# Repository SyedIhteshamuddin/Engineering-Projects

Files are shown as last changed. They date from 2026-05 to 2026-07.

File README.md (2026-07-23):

# Electrical Circuit Projects

This repository contains some of the Arduino and Tinkercad projects I’ve been building while learning embedded systems, sensors, and basic automation concepts.

Most of these projects started as small experiments and gradually improved as I learned more about how sensors, outputs, and system logic work together.

---

## Current Projects

### SAN - (Smart Assistive Navigator)
An assistive navigation system designed to help visually impaired users detect obstacles and unsafe walking surfaces using real-time ultrasonic sensing

### Adaptive Smart Light System
A simple automatic street light simulation using an LDR sensor and adaptive LED brightness control.

### Smart Gas Leakage System
A gas monitoring and alert system that detects gas levels and responds using LEDs, LCD messages, and a buzzer alarm.

More projects and experiments will be added over time as I continue learning.

---

## Project Files

Each project folder usually contains:

- `.ino` file → Arduino code for the project
- `.mp4` file → working demo/simulation video
- `.png` file → circuit design screenshot
- `bom.csv` → components used in the circuit
- `README.md` → explanation of how the project works

---

## Tools Used

- Arduino Uno
- Tinkercad Circuits
- Arduino Blocks + C++
- Sensors, LEDs, buzzers, LCDs, and other basic components

---
## Certificates & Learning

This repository also includes a few engineering-related certificates and learning records connected to:

- MITx Certificate
-Circuit Analysis
-Electronics

- MATLAB
-automation
-embedded systems
-engineering software/tools

- Altium PCB Design Course
 -PCB Designing
 -PCB Manufacturing
 -PCB Simulation

Check Certifications Folder for more details.
---

## Why I Started This Repository

I created this repository to document my progress while exploring electronics and embedded systems.

Right now I’m mainly focused on:
- sensor-based systems
- automation concepts
- Arduino projects
- circuit simulation
- learning how different components interact in a complete system

I’ll continue updating this repository as I build more projects and improve my understanding.

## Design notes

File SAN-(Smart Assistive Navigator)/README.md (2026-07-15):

# Smart Assistive Navigator (SAN)

SAN 1

---






---
## Project Overview
* SAN is An assistive navigation system designed to help visually impaired users detect obstacles and unsafe walking surfaces using real-time ultrasonic sensing.*

Instead of relying on a single warning mechanism, the system communicates danger through **vibration**, **audio alerts**, and a **16×2 LCD**, allowing users to receive immediate feedback depending on the surrounding environment.

The project was developed to explore how embedded systems and simple sensors can be combined to solve real-world accessibility problems.

---
## Demo Video

https://github.com/user-attachments/assets/2c6f290e-6d18-4922-b412-0dd310eef9df

# Problem Statement

Millions of visually impaired individuals rely on traditional white canes for navigation.

While effective for nearby obstacles, they often provide limited awareness of:

- obstacles at head level
- objects farther ahead
- sudden drops
- stairs
- potholes

This project explores a low-cost embedded solution capable of providing earlier warnings through intelligent sensing.

---

# Our Solution

```
          Walking Path
                │
                ▼

     Front Ultrasonic Sensor
                │
                ▼
         Arduino UNO
                │
                │
     Ground Ultrasonic Sensor
                │
                ▼
      Intelligent Decision System
                │
      ┌─────────┼─────────┐
      ▼         ▼         ▼
   LCD      Vibrator    Buzzer
```
## Features

- Dual ultrasonic sensing

- Real-time obstacle detection

- Drop detection

- Adaptive audio alerts

- Adaptive vibration feedback

- LCD monitoring

- Sensor fault detection

- Median filtering

- Boot self-test

- Modular firmware

---
## Hardware Table

| Component | Qty | Purpose |
| --- | --: | --- |
| Arduino Uno | 1 | Main controller |
| HC-SR04 Ultrasonic Sensor | 2 | Obstacle & drop detection |
| 16×2 LCD | 1 | System status |
| Vibration Motor | 1 | Haptic feedback |
| Piezo Buzzer | 1 | Audio feedback |
| NPN Transistor | 1 | Motor driver |
| Breadboard | 1 | Prototype |
| Jumper Wires | — | Connections |

---

SAN - (Smart Assistive Navigator)

---
## Firmware Workflow

```
Read Sensors
      │
      ▼
Filter Sensor Readings
      │
      ▼
Determine Navigation State
      │
      ├── SAFE
      ├── NEAR
      ├── CRITICAL
      ├── DROP
      └── SENSOR ERROR
      │
      ▼
Update LCD
      │
      ▼
Generate Audio & Haptic Alerts
```
---  
## System Workflow

```text
        ┌──────────────┐
        │    START     │
        └──────┬───────┘
               │
               ▼
 Read Front & Ground Sensors
               │
               ▼
    Median Noise Filtering
               │
               ▼
 Navigation State Machine
               │
      ┌────────┼────────┐
      ▼        ▼        ▼
 LCD Update  Vibrator  Buzzer
               │
               ▼
          Repeat Loop
```

---

## Alert System

| State | Vibration | Buzzer |
| --- | --- | --- |
| SAFE | Off | Off |
| NEAR | Slow pulses | Slow beeps |
| CRITICAL | Fast pulses | Fast beeps |
| DROP | Long vibration | High-frequency warning |
| SENSOR ERROR | Error pulse | Error tone |

---
## Repository Structure

```text
Smart-Assistive-Navigator/
│
├── Firmware/
│   └── SAN.ino
│
├── Circuit/
│   └── Tinkercad Design
│
├── Images/
│   ├── Hero.png
│   ├── Circuit.png
│   └── Workflow.png
│
├── Demo/
│   └── Demo.mp4
│
├── BOM/
│   └── Bill_of_Materials.pdf
│
└── README.md
```
---
## Software Architecture

```text
loop()
│
├── Sensor Module
│   ├── Front Sensor
│   └── Ground Sensor
│
├── Signal Processing
│   └── Median Filter
│
├── Decision Engine
│   └── Finite State Machine
│
├── Display Manager
│
├── Alert Controller
│   ├── Vibration Motor
│   └── Piezo Buzzer
│
└── Serial Debug
```
---

## Software Design

The firmware is divided into independent modules to keep the code organized and easier to maintain.

* Sensor acquisition
* Distance filtering
* Navigation state machine
* LCD display manager
* Alert controller
* Boot diagnostics
* Serial debugging

This modular structure made testing and debugging significantly easier during development.

## Engineering Challenges

During development several practical challenges had to be solved:

- Filtering noisy ultrasonic sensor readings
- Preventing false stair detection
- Stabilizing state transitions using hysteresis
- Handling temporary sensor failures
- Designing distinct vibration and buzzer patterns
- Organizing firmware into modular components for easier debugging

## Safety Features

* Sensor failure handling
* Invalid reading rejection
* Cached sensor recovery
* Hysteresis for stable state transitions
* Startup hardware self-test
* Real-time status display

---
## Key Specifications

| Specification | Value |
|---|---|
| Controller | Arduino Uno |
| Programming Language | Embedded C++ |
| Sensors | 2 × HC-SR04 |
| Detection Range | 2–300 cm |
| Drop Detection Threshold | 22 cm |
| Feedback | LCD + Vibration + Buzzer |
| Firmware Architecture | Finite State Machine |
| Signal Processing | Median Filter |

## Future Improvements

Although the current prototype demonstrates the core navigation system, future versions could include:

- Rechargeable battery management

- Waterproof housing

- Voice feedback

- Bluetooth diagnostics

- Lightweight wearable PCB

## What I Learned

Building this project taught me much more than simply connecting sensors to an Arduino.

One thing I didn't expect was how difficult it was to make the sensors reliable. Early versions constantly jumped between states because ultrasonic readings fluctuated. I eventually solved this by combining median filtering, hysteresis, and cached readings instead of relying on raw sensor values. That experience taught me that reliability often comes from small engineering decisions rather than adding more hardware.

Perhaps the biggest lesson was that making a system *reliable* is often more difficult than making it simply *work*.

## Current Status

| Status | Progress |
|---|---|
| Prototype | ✅ Complete |
| Firmware | ✅ Complete |
| Simulation | ✅ Tested |
| Documentation | ✅ Complete |
| Demo Video | ✅ Available |
| GitHub Repository | ✅ Public |
---

## Author

**Syed Ihteshamuddin**

Class 12 Student

Interested in Embedded Systems, Electrical Engineering, and Assistive Technologies.

## Feedback

If you have suggestions, ideas, or improvements for this project, feel free to open an issue or reach out. Constructive feedback is always welcome.
---
## License

This project is shared for educational purposes.

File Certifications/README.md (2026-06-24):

# Certificates

This folder contains certificates completed while exploring engineering tools and technical concepts related to electronics and embedded systems.

Only relevant certifications connected to engineering and technical learning are added here.

---

# Current Certificate

# MITx 6.002.1x: Circuits and Electronics 1

## [MITx 6.002.1x Certificate _ edX.pdf](https://github.com/user-attachments/files/29301755/MITx.6.002.1x.Certificate._.edX.pdf)

---

# MATLAB Onramp

Introductory MATLAB course completed through MathWorks Training Services.
https://matlabacademy.mathworks.com/progress/share/certificate.html?id=902a0990-0046-441e-aec8-c9c82dd8b052&

 ## Next Steps

This repository serves as a foundation for future projects involving

- MATLAB
- Circuit Simulation
- Signal Processing
- Embedded Systems
- Electronics Design

The certificate file is included in this folder.

---

### More learning records and certificates may be added gradually while exploring new engineering concepts and software tools.

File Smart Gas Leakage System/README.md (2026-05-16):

Smart Gas Leakage System

This project is an Arduino + Tinkercad based gas monitoring and alert system built while learning embedded systems and automation concepts.

The system continuously monitors gas levels using a gas sensor and responds with different warning stages based on gas concentration.

---

# Features

- Real-time gas monitoring
- Multi-level gas detection
- SAFE / WARNING / DANGER indication
- LCD status display
- LED alert indicators
- Buzzer alarm during dangerous gas levels
- Serial monitor live sensor values

---

# Components Used

- Arduino Uno
- Gas Sensor
- LCD Display (16x2 I2C)
- LEDs
- Buzzer
- Resistors
- Breadboard
- Tinkercad Circuits
Smart Gas Leakage System
---

# How The System Works

The gas sensor continuously reads surrounding gas concentration levels.

Depending on the sensor value:

- SAFE level → Green LED turns ON
- WARNING level → Yellow LED turns ON
- DANGER level → Red LED + buzzer alarm activate

The LCD display shows:
- current system status
- live gas sensor value

This creates a simple simulation of an automated gas leakage warning system.

---

# Threshold Levels

| Gas Value | System Status |
|---|---|
| Below 307 | No Gas Detected |
| 307 - 499 | SAFE |
| 500 - 699 | WARNING |
| 700+ | DANGER |

---

# What I Learned

While building this project, I learned:

- basics of gas sensors
- analog sensor readings
- threshold-based system logic
- LCD interfacing
- buzzer integration
- multi-output embedded system behavior
- how monitoring systems react to environmental conditions

I also improved my understanding of how sensors, outputs, and decision-making logic work together in embedded systems.

---

# Future Improvements

Some improvements I may explore later:

- GSM alert system
- IoT monitoring
- mobile notifications
- automatic ventilation system
- real hardware implementation

---

# Project Preview



---

# Built Using

- Arduino
- Tinkercad Circuits
- Arduino Blocks + C++

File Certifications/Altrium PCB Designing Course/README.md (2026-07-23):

# Basic PCB Designing Course

**Issued by:** Altium Education

## Overview

Completed the Basic PCB Designing Course provided by Altium Education to learn the fundamentals of professional PCB design.

The course introduces the complete PCB design workflow, from creating schematics to preparing a board for manufacturing.

## Topics Covered

- PCB design fundamentals
- Schematic capture
- PCB layout
- PCB footprints
- Component libraries
- Bill of Materials (BOM)
- Manufacturing workflow
- Basic ECAD concepts

## Why I Took This Course

After building several Arduino projects on breadboards and in Tinkercad, I wanted to learn how electronic products are actually designed for manufacturing.

This course gave me the theoretical foundation needed to begin designing custom PCBs.

## Next Step

I will be applying these concepts by redesigning my **Smart Assistive Navigator (SAN)** project as a custom PCB using **KiCad**, with the goal of producing a manufacturing-ready design.

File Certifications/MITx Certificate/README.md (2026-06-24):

# MITx 6.002.1x: Circuits and Electronics 1

## [MITx 6.002.1x Certificate _ edX.pdf](https://github.com/user-attachments/files/29301755/MITx.6.002.1x.Certificate._.edX.pdf)

## Overview

This repository documents the successful completion of **MITx 6.002.1x: Circuits and Electronics 1 – Basic Circuit Analysis**, offered through MITx and edX.

The course provided a strong foundation in electrical engineering principles and analytical problem solving.

---

## Topics Covered

- Kirchhoff's Current Law (KCL)
- Kirchhoff's Voltage Law (KVL)
- Nodal Analysis
- Thevenin & Norton Equivalents
- Dependent Sources
- Nonlinear Circuits
- Operational Amplifiers
- MOS Logic Fundamentals

---

## Skills Developed

- Circuit Analysis
- Electrical Engineering Fundamentals
- Problem Solving
- Analytical Thinking
- Engineering Mathematics

---

## Certificate

The certificate can be found in:

```
[MITx 6.002.1x Certificate _ edX.pdf](https://github.com/user-attachments/files/29301765/MITx.6.002.1x.Certificate._.edX.pdf)

```

---

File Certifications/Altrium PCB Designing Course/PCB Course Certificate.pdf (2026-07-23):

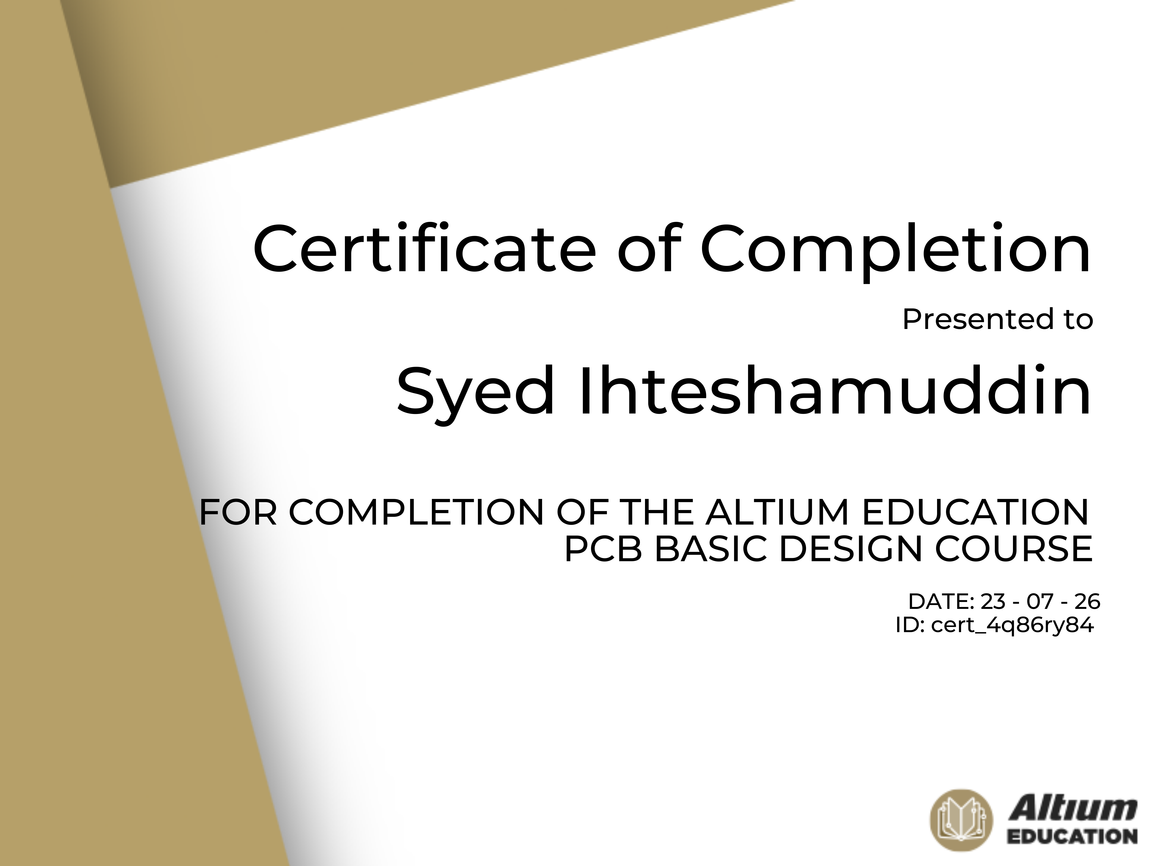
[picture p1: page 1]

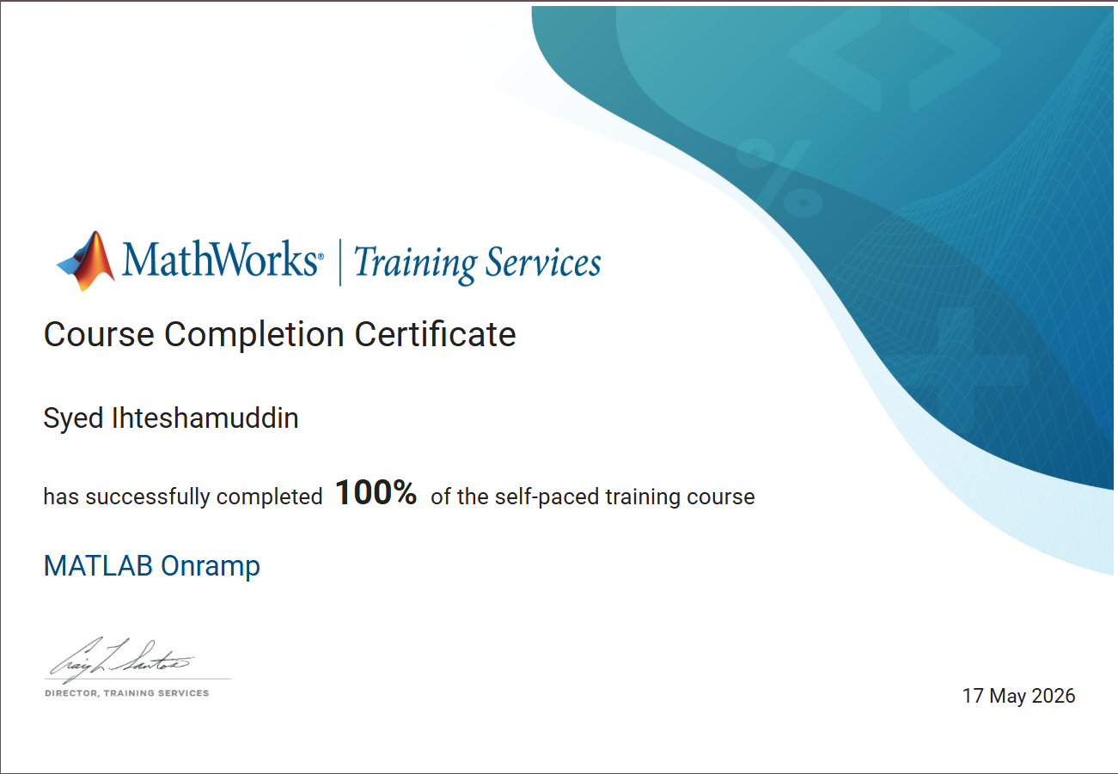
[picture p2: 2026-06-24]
Certifications/MATLAB Onramp/MATLAB Syed Ihteshamuddin Certificate.png

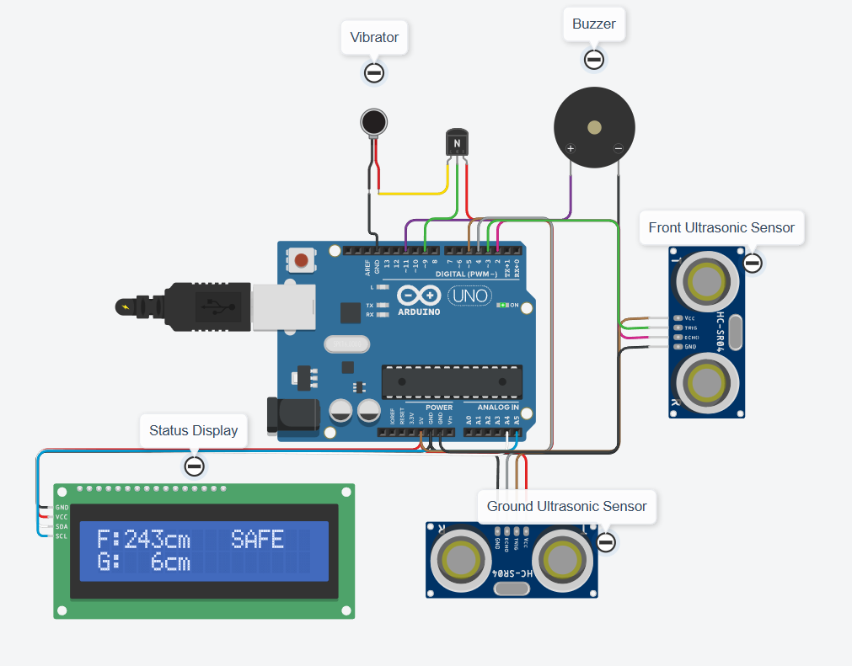
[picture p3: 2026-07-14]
SAN-(Smart Assistive Navigator)/SAN_Hero.png

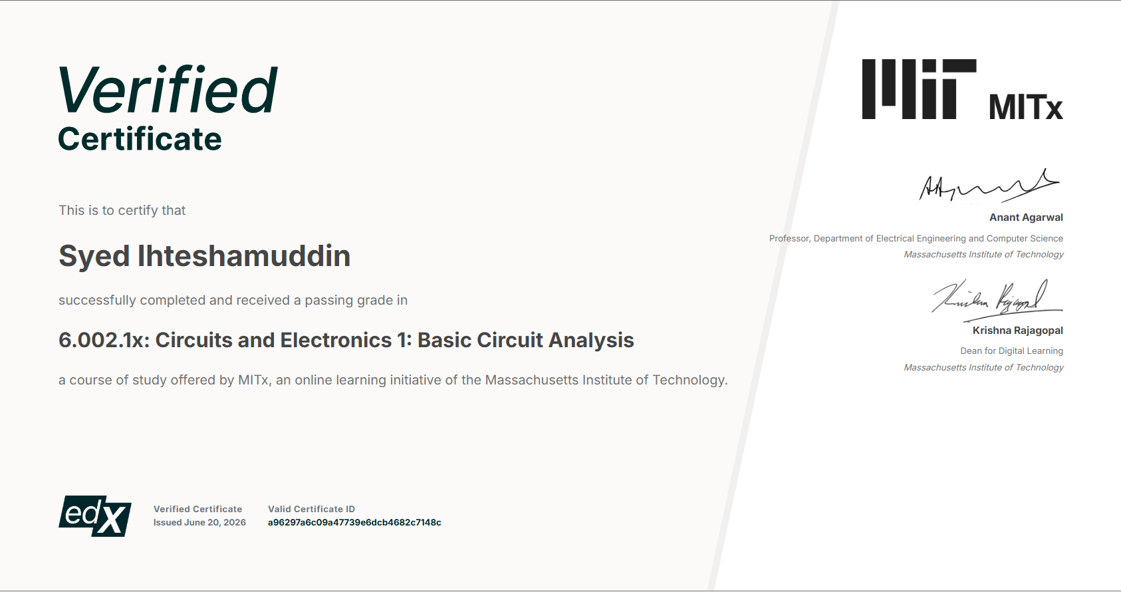
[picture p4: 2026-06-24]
Certifications/MITx Certificate/MIT certificate Photo.png

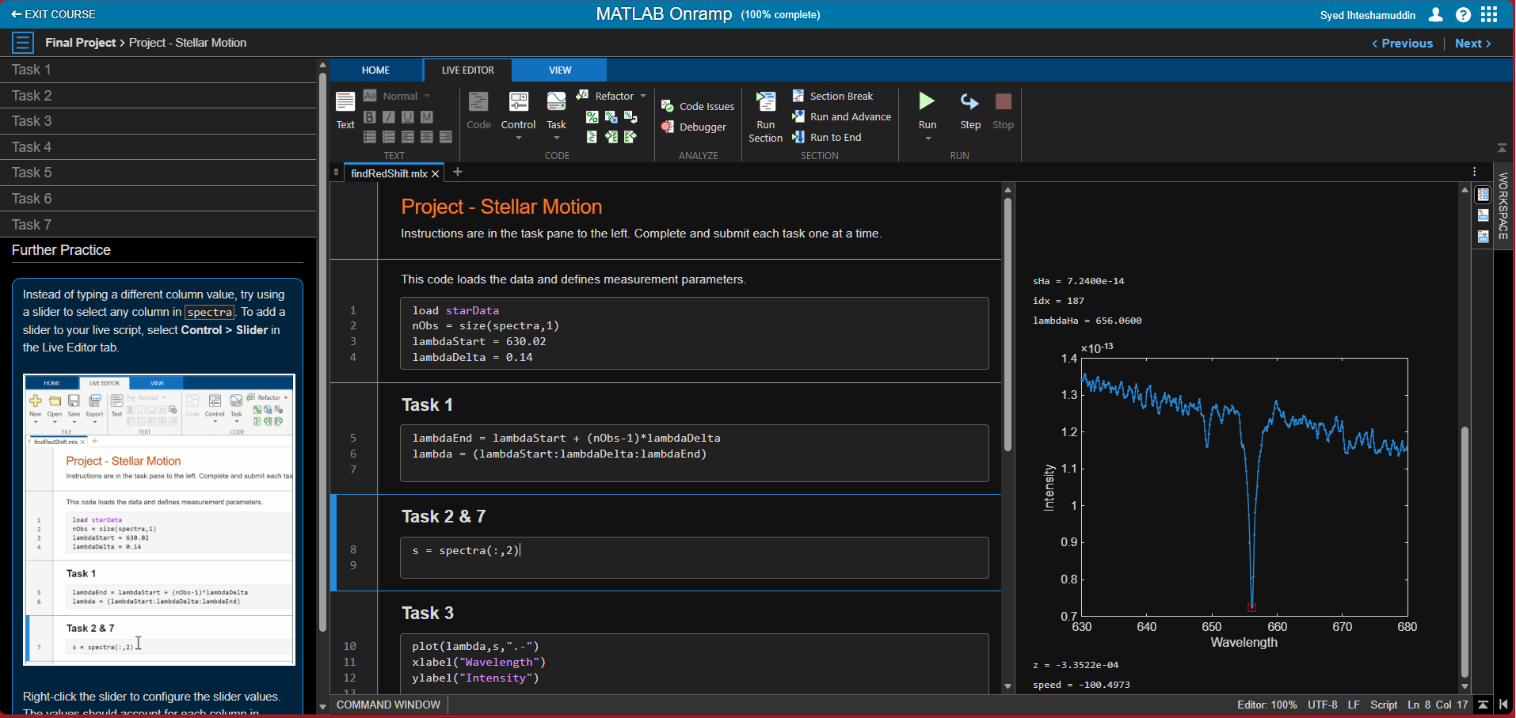
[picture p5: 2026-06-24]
Certifications/MATLAB Onramp/Matlab dashboard.png

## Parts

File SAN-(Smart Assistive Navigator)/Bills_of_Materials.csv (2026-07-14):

Name | Quantity | Component
U1 | 1 | Arduino Uno R3
M1 | 1 | Vibration Motor
T1 | 1 | NPN Transistor (BJT)
PIEZO1 | 1 | Piezo
DISTGroundDistance Measurer, DISTFront Obstacle Measurer | 2 | Ultrasonic Distance Sensor (4-pin)
U2 | 1 | MCP23008-based, 39 (0x27) LCD 16 x 2 (I2C)

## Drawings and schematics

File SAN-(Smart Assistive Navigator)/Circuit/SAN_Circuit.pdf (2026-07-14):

A

1 | 2 | 3 | 4 | 5 | 6

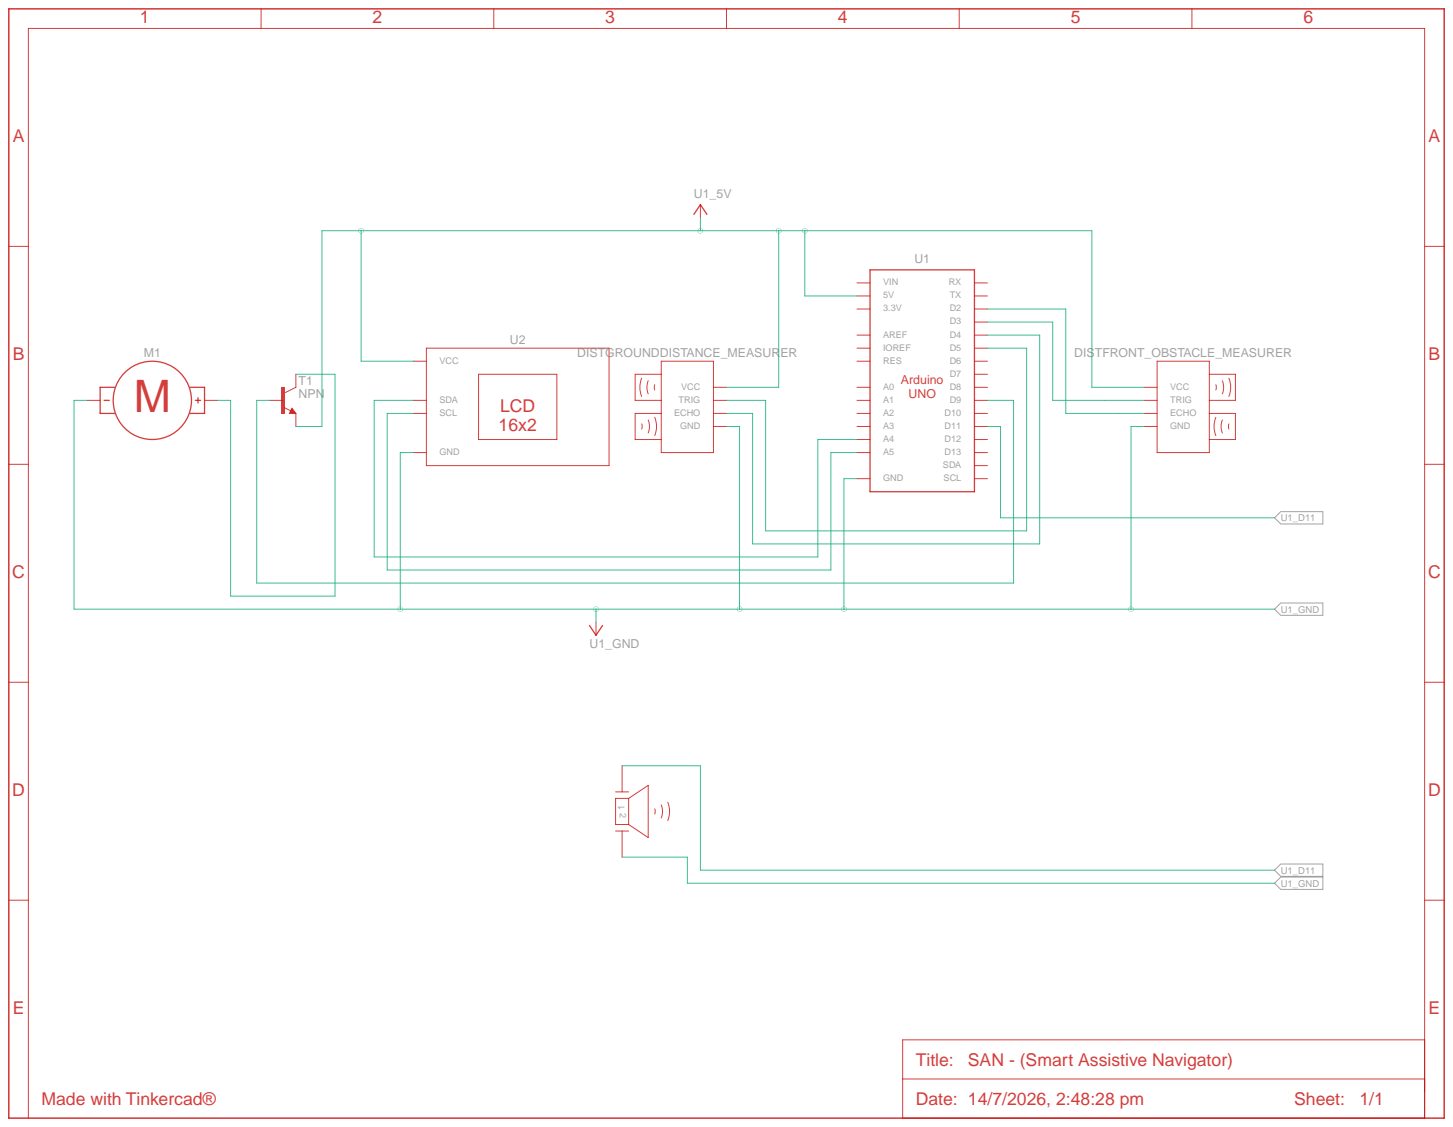
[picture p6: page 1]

Title: SAN - (Smart Assistive Navigator)

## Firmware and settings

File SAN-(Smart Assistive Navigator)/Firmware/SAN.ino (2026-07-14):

/*
===============================================================================
                     SMART ASSISTIVE NAVIGATOR (SAN)
===============================================================================

Firmware Version : 1.0 RC1
Author           : Syed Ihteshamuddin
Platform         : Arduino UNO (ATmega328P)

Project Overview
----------------
Smart Assistive Navigator (SAN) is an embedded assistive mobility system
designed to improve obstacle awareness and drop-off detection for visually
impaired users.

The system continuously monitors the environment using dual ultrasonic sensors,
processes measurements through a robust filtering algorithm, classifies hazards
using a finite state machine with hysteresis, and provides intuitive haptic and
auditory feedback in real time.

===============================================================================
Hardware Configuration
===============================================================================

Microcontroller
---------------
• Arduino UNO R3

Sensors
-------
• HC-SR04 Ultrasonic Sensor (Front Obstacle Detection)
• HC-SR04 Ultrasonic Sensor (Ground / Drop Detection)

Output Devices
--------------
• 16×2 LCD Display (I²C Backpack)
• Vibration Motor
• Piezo Buzzer

===============================================================================
System Features
===============================================================================

✓ Dual Ultrasonic Navigation
✓ Obstacle Detection
✓ Stair / Drop Detection
✓ Median-Based Sensor Filtering
✓ Sensor Failure Recovery
✓ Finite State Machine with Hysteresis
✓ Non-blocking Alert Engine
✓ Intelligent LCD Update Manager
✓ Boot Self-Test Routine
✓ State Transition Alerts
✓ Serial Debug Interface

===============================================================================
Navigation States
===============================================================================

SAFE          : Normal walking condition
NEAR          : Obstacle approaching
CRITICAL      : Immediate obstacle warning
DROP          : Stair / Edge detected
SENSOR_ERROR  : Sensor communication failure

===============================================================================
Pin Configuration
===============================================================================

Front Ultrasonic
----------------
Trigger : D3
Echo    : D2

Ground Ultrasonic
-----------------
Trigger : D5
Echo    : D4

Output Devices
--------------
Motor  : D9
Buzzer : D11

LCD
---
I²C Backpack

===============================================================================
Copyright
===============================================================================

Developed as an independent embedded systems project for educational,
engineering portfolio, and assistive technology research purposes.

===============================================================================
*/

#include <Adafruit_LiquidCrystal.h>

Adafruit_LiquidCrystal lcd(7);

// ---------------- PIN DEFINITIONS ----------------

const byte FRONT_TRIG = 3;
const byte FRONT_ECHO = 2;

const byte GROUND_TRIG = 5;
const byte GROUND_ECHO = 4;

const byte MOTOR_PIN = 9;
const byte BUZZER_PIN = 11;

//---------------- THRESHOLDS ----------------

const int SAFE_DISTANCE = 150;
const int SAFE_EXIT     = 160;

const int CRITICAL_DISTANCE = 75;
const int CRITICAL_EXIT     = 85;

const int DROP_DISTANCE = 22;
const int DROP_EXIT     = 14;

// ---------------- STATES ----------------

enum NavigationState
{
  SAFE,
  NEAR,
  CRITICAL,
  DROP,
  SENSOR_ERROR
};

NavigationState currentState = SAFE;
NavigationState previousState = SENSOR_ERROR;

// ---------------- DISTANCES ----------------

int frontDistance = 0;
int groundDistance = 0;

// ---------------- SENSOR CACHE ----------------

int lastFrontDistance = 150;
int lastGroundDistance = 10;

byte frontFailCount = 0;
byte groundFailCount = 0;

const byte MAX_SENSOR_FAILURES = 5;

byte dropDetectCount = 0;
byte dropClearCount = 0;

const byte DROP_CONFIRM_COUNT = 3;
const byte DROP_CLEAR_COUNT = 3;


//--------------------------------------------------
// LCD CACHE
//--------------------------------------------------

int oldFront = -999;
int oldGround = -999;

NavigationState oldLCDState = SENSOR_ERROR;

// --------------------------------------------------
// ALERT ENGINE VARIABLES
// --------------------------------------------------

unsigned long alertTimer = 0;
unsigned long lcdTimer = 0;

bool alertOutput = LOW;

int alertOnTime = 0;
int alertOffTime = 0;

int buzzerFrequency = 0;


//---------- GLOBAL OUTPUT CONTROL VARIABLES------------



long readUltrasonic(byte trigPin, byte echoPin)
{
  pinMode(trigPin, OUTPUT);

  digitalWrite(trigPin, LOW);
  delayMicroseconds(2);

  digitalWrite(trigPin, HIGH);
  delayMicroseconds(10);

  digitalWrite(trigPin, LOW);

  pinMode(echoPin, INPUT);

  long duration = pulseIn(echoPin, HIGH, 30000);

  if(duration==0)
      return -1;

  return duration;
}

// --------------------------------------------------

int getDistanceCM(byte trig, byte echo)
{
    long duration = readUltrasonic(trig, echo);

    if (duration == -1)
        return -1;

    int distance = duration * 0.01723;

    if (distance < 2 || distance > 300)
        return -1;

    return distance;
}

// --------------------------------------------------
// SENSOR ACQUISITION & FILTERING
// --------------------------------------------------

int medianDistance(byte trig, byte echo)
{
    int sample[3];
    int validCount = 0;

    // Collect three readings
    for(int i = 0; i < 3; i++)
    {
        int d = getDistanceCM(trig, echo);

        if(d != -1)
        {
            sample[validCount++] = d;
        }

        delay(2);
    }

    // No valid readings
    if(validCount == 0)
        return -1;

    // One valid reading
    if(validCount == 1)
        return sample[0];

    // Two valid readings
    if(validCount == 2)
        return (sample[0] + sample[1]) / 2;

    // Three valid readings -> median
    if(sample[0] > sample[1])
    {
        int t = sample[0];
        sample[0] = sample[1];
        sample[1] = t;
    }

    if(sample[1] > sample[2])
    {
        int t = sample[1];
        sample[1] = sample[2];
        sample[2] = t;
    }

    if(sample[0] > sample[1])
    {
        int t = sample[0];
        sample[0] = sample[1];
        sample[1] = t;
    }

    return sample[1];
}
//--------------------------------------------------
// Reads and validates ultrasonic sensor data.
//--------------------------------------------------
void readSensors()
{
    int newFront = medianDistance(FRONT_TRIG, FRONT_ECHO);
    int newGround = medianDistance(GROUND_TRIG, GROUND_ECHO);

    //---------------- FRONT SENSOR ----------------

    if(newFront == -1)
    {
        frontFailCount++;

        if(frontFailCount >= MAX_SENSOR_FAILURES)
            frontDistance = -1;
        else
            frontDistance = lastFrontDistance;
    }
 else
{
    frontFailCount = 0;
    frontDistance = newFront;
    lastFrontDistance = newFront;
}
    //---------------- GROUND SENSOR ----------------

    if(newGround == -1)
    {
        groundFailCount++;

        if(groundFailCount >= MAX_SENSOR_FAILURES)
            groundDistance = -1;
        else
            groundDistance = lastGroundDistance;
    }
  else
{
    groundFailCount = 0;
    groundDistance = newGround;
    lastGroundDistance = newGround;
}
  }

//--------------------------------------------------
// NAVIGATION STATE MACHINE (HYSTERESIS)
//--------------------------------------------------

// Determines navigation state using hysteresis.

void determineState()
 {
    if(frontDistance == -1 || groundDistance == -1)
{
    currentState = SENSOR_ERROR;
    return;
}

    switch(currentState)
    {

        //---------------- SAFE ----------------

        case SAFE:

            if(groundDistance > DROP_DISTANCE)
{
    dropDetectCount++;

    if(dropDetectCount >= DROP_CONFIRM_COUNT)
    {
        currentState = DROP;
        dropDetectCount = 0;
    }
}
else
{
    dropDetectCount = 0;

    if(frontDistance < CRITICAL_DISTANCE)
        currentState = CRITICAL;
    else if(frontDistance < SAFE_DISTANCE)
        currentState = NEAR;
}
           

            break;


        //---------------- NEAR ----------------

        case NEAR:

            if(groundDistance > DROP_DISTANCE)
            {
                currentState = DROP;
            }
            else if(frontDistance < CRITICAL_DISTANCE)
            {
                currentState = CRITICAL;
            }
            else if(frontDistance > SAFE_EXIT)
            {
                currentState = SAFE;
            }

            break;


        //---------------- CRITICAL ----------------

        case CRITICAL:

            if(groundDistance > DROP_DISTANCE)
            {
                currentState = DROP;
            }
            else if(frontDistance > CRITICAL_EXIT)
            {
                currentState = NEAR;
            }

            break;


        //---------------- DROP ----------------

       case DROP:

    if(groundDistance < DROP_EXIT)
    {
        dropClearCount++;

        if(dropClearCount >= DROP_CLEAR_COUNT)
        {
            dropClearCount = 0;

            if(frontDistance < CRITICAL_DISTANCE)
                currentState = CRITICAL;
            else if(frontDistance < SAFE_DISTANCE)
                currentState = NEAR;
            else
                currentState = SAFE;
        }
    }
    else
    {
        dropClearCount = 0;
    }

    break;


        //---------------- SENSOR ERROR ----------------

        case SENSOR_ERROR:

            currentState = SAFE;

            break;
    }
}
//--------------------------------------------------
// LCD USER INTERFACE
//--------------------------------------------------

// Updates LCD only when displayed values change.

void updateLCD()
{
    char buffer[17];

    // ---------- Front Distance ----------

    if(frontDistance != oldFront)
{
    lcd.setCursor(0,0);

    if(frontDistance == -1)
    {
        lcd.print("F:---cm ");
    }
    else
    {
        sprintf(buffer,"F:%3dcm", frontDistance);
        lcd.print("        ");
        lcd.setCursor(0,0);
        lcd.print(buffer);
    }

    oldFront = frontDistance;
}
    // ---------- Ground Distance ----------

    if(groundDistance != oldGround)
{
    lcd.setCursor(0,1);

    if(groundDistance == -1)
    {
        lcd.print("G:---cm ");
    }
    else
    {
        sprintf(buffer,"G:%3dcm", groundDistance);
        lcd.print("        ");
        lcd.setCursor(0,1);
        lcd.print(buffer);
    }

    oldGround = groundDistance;
}
  

    // ---------- Navigation State ----------

    if(currentState != oldLCDState)
    {
        lcd.setCursor(10,0);
        lcd.print("      ");        // erase old state
        lcd.setCursor(10,0);

        switch(currentState)
        {
            case SAFE:
                lcd.print("SAFE");
                break;

            case NEAR:
                lcd.print("NEAR");
                break;

            case CRITICAL:
                lcd.print("STOP");
                break;

            case DROP:
                lcd.print("DROP");
                break;

          case SENSOR_ERROR:
    lcd.print("ERROR");
    break;
        }

        oldLCDState = currentState;
    }
}
// --------------------------------------------------

void serialDebug()
{

    Serial.print("Front : ");

    Serial.print(frontDistance);

    Serial.print(" cm | Ground : ");

    Serial.print(groundDistance);

    Serial.print(" cm | State : ");

    switch(currentState)
    {

      case SAFE:

        Serial.println("SAFE");

      break;

      case NEAR:

        Serial.println("NEAR");

      break;

      case CRITICAL:

        Serial.println("CRITICAL");

      break;

      case DROP:

        Serial.println("DROP");

      break;

      case SENSOR_ERROR:

        Serial.println("ERROR");

      break;
      
    
    }

}

void playTransitionAlert()
{
    switch(currentState)
    {
        case SAFE:

            tone(BUZZER_PIN,800);
            delay(25);
            noTone(BUZZER_PIN);

            break;


        case NEAR:

            digitalWrite(MOTOR_PIN,HIGH);
            delay(40);
            digitalWrite(MOTOR_PIN,LOW);

            break;


        case CRITICAL:

            for(byte i=0;i<2;i++)
            {
                tone(BUZZER_PIN,1500);
                delay(20);
                noTone(BUZZER_PIN);
                delay(15);
            }

            break;


        case DROP:

            digitalWrite(MOTOR_PIN,HIGH);
            tone(BUZZER_PIN,2200);

            delay(120);

            digitalWrite(MOTOR_PIN,LOW);
            noTone(BUZZER_PIN);

            break;


        case SENSOR_ERROR:

            for(byte i=0;i<3;i++)
            {
                tone(BUZZER_PIN,400);
                delay(15);
                noTone(BUZZER_PIN);
                delay(10);
            }

            break;
    }
}

// --------------------------------------------------
// ALERT ENGINE
// --------------------------------------------------

// Generates vibration and buzzer alert patterns.

void updateAlerts()
{
    unsigned long now = millis();
  
  if(currentState != previousState)
{
    alertOutput = LOW;
    alertTimer = 0;
}

    switch(currentState)
    {

        //---------------- SAFE ----------------

        case SAFE:

            digitalWrite(MOTOR_PIN, LOW);
            noTone(BUZZER_PIN);
            alertOutput = LOW;
            alertTimer = millis();   // reset timer
            return;

        //---------------- SENSOR ERROR ----------------

        case SENSOR_ERROR:

            alertOnTime = 150;
            alertOffTime = 150;
            buzzerFrequency = 300;

            break;

        //---------------- NEAR ----------------

        case NEAR:

            alertOnTime = 250;
            alertOffTime = 750;
            buzzerFrequency = 900;

            break;

        //---------------- CRITICAL ----------------
      case CRITICAL :
alertOnTime = 120;
alertOffTime = 120;
buzzerFrequency = 1500;

            break;

        //---------------- DROP ----------------

        case DROP:

            alertOnTime = 500;
            alertOffTime = 200;
            buzzerFrequency = 2200;

            break;
    }

    if(alertOutput)
    {
        if(now-alertTimer>=alertOnTime)
        {
            alertTimer=now;

            alertOutput=LOW;

            digitalWrite(MOTOR_PIN,LOW);

            noTone(BUZZER_PIN);
        }
    }
    else
    {
        if(now-alertTimer>=alertOffTime)
        {
            alertTimer=now;

            alertOutput=HIGH;

            digitalWrite(MOTOR_PIN,HIGH);

            tone(BUZZER_PIN,buzzerFrequency);
        }
    }
}

//--------------------------------------------------
// BOOT SELF TEST
//--------------------------------------------------

void bootSelfTest()
{
    lcd.clear();

    lcd.setCursor(0,0);
    lcd.print("SYSTEM CHECK");

    lcd.setCursor(0,1);
    lcd.print("LCD......OK");

    delay(250);

    lcd.setCursor(0,1);
    lcd.print("FRONT....");

    if(getDistanceCM(FRONT_TRIG, FRONT_ECHO) != -1)
        lcd.print("OK");
    else
        lcd.print("FAIL");

    delay(250);

    lcd.setCursor(0,1);
    lcd.print("GROUND...");

    if(getDistanceCM(GROUND_TRIG, GROUND_ECHO) != -1)
        lcd.print("OK");
    else
        lcd.print("FAIL");

    delay(250);

    lcd.setCursor(0,1);
    lcd.print("MOTOR....OK");

    delay(200);

    lcd.setCursor(0,1);
    lcd.print("BUZZER...OK");

    tone(BUZZER_PIN,1200);
    delay(100);
    noTone(BUZZER_PIN);

    delay(200);

    lcd.clear();

    lcd.setCursor(0,0);
    lcd.print(" SYSTEM READY");

    lcd.setCursor(0,1);
    lcd.print("Have a Safe Walk");

    delay(600);

    lcd.clear();
}

// --------------------------------------------------

void setup()
{

    Serial.begin(9600);
  
    Serial.println("===== BOOT =====");

    lcd.begin(16,2);

    pinMode(MOTOR_PIN,OUTPUT);

    pinMode(BUZZER_PIN,OUTPUT);

    lcd.clear();
  
    oldFront = -999;
  
    oldGround = -999;
  
    oldLCDState = SENSOR_ERROR;

    lcd.setCursor(0,0);

    lcd.print(" Smart Assistive ");

    lcd.setCursor(0,1);

    lcd.print(" Navigator ");

    delay(1500);

    lcd.clear();
  
    bootSelfTest();

}

// --------------------------------------------------

void loop()

{
  readSensors();


    determineState();
 
  if(currentState != previousState)
{
    playTransitionAlert();
}
  

    if (millis() - lcdTimer >= 100)
{
    lcdTimer = millis();
    updateLCD();
}


    updateAlerts();


    serialDebug();


    previousState = currentState;


    delay(50);  
}  

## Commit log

2026-07-14 Rename SAN - (Smart Assistive Navigator).brd to SAN_Circuit.brd
    [SAN_Circuit.brd]
2026-07-23 Rename certificate-of-completion-for-altium-education-cumulative-quiz.pdf to PCB Course Certificate.pdf
